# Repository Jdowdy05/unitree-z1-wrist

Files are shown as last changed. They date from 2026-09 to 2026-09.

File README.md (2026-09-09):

# Unitree Z1 wrist

A two-axis, 3D-printable wrist mechanism for the Unitree Z1, using four
ROBOTIS DYNAMIXEL XL330-M288-T servos. Two opposed servos drive each axis through
1:1 connections to their factory horns; there are no external gears or belts.

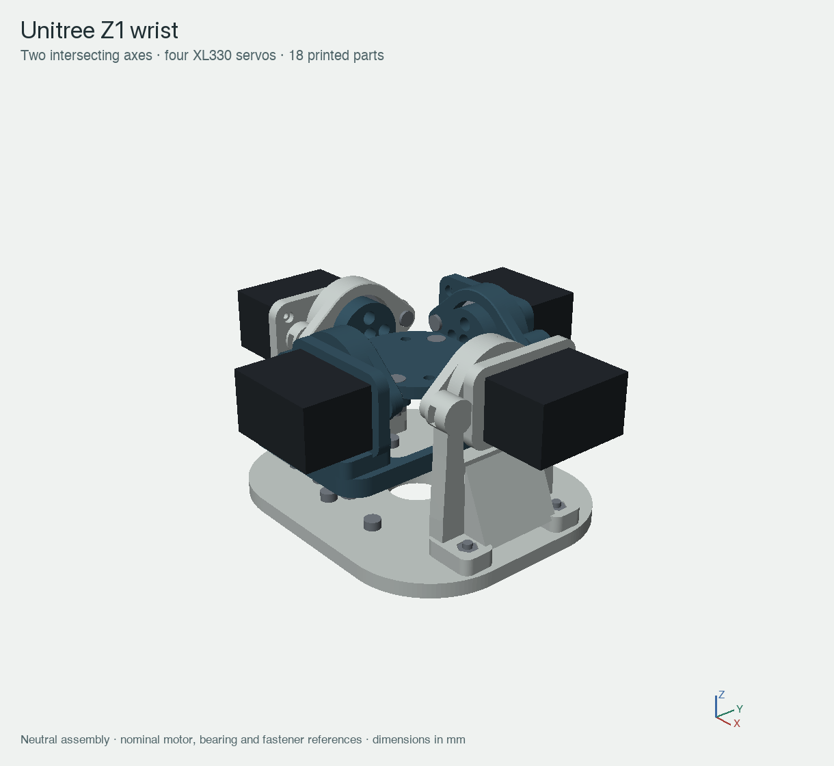
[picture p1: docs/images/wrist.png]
Assembled wrist


**Prototype hardware:** check printed fits, cable clearance and operating loads
before use. No working payload or continuous-duty rating has been established.

## Start here

- **Print:** download the files in [stl/](stl/). Print one of each of the 18 files.
- **Edit in CAD:** open [cad/wrist.step](cad/wrist.step) in your CAD application,
  or [cad/wrist.FCStd](cad/wrist.FCStd) in FreeCAD.
- **Modify individual pieces:** use the named STEP files in [cad/parts/](cad/parts/).
- **Build:** follow the [assembly guide](docs/assembly.md) and [BOM](BOM.csv).
- **Download everything:** use [Download ZIP](https://github.com/Jdowdy05/unitree-z1-wrist/archive/refs/heads/main.zip),
  or clone this repository.

```sh
git clone https://github.com/Jdowdy05/unitree-z1-wrist.git
```

## Layout

```text
cad/
  wrist.FCStd           Native FreeCAD assembly, grouped by part type
  wrist.step            Complete assembly for other CAD applications
  parts/                18 individual printable-part STEP models
  source/
    Rebuild_Wrist.FCMacro
    dimensions.json     Main layout dimensions
  geometry.json         Export inventory, dimensions and mesh checks
stl/                    18 separate meshes in starting print orientations
docs/
  assembly.md           Assembly order, screw locations and print notes
  images/               Assembly and bearing-stack illustrations
BOM.csv                 Mechanical parts and purchased hardware
LICENSE
```

The assembly contains the wrist mechanism, a general-purpose recessed output
plate and nominal reference shapes for motors, bearings and M3 hardware.
The STL directory contains printable parts only. Purchased parts are not
included as printable meshes.

## Main dimensions

| Feature | Nominal value |
| --- | --- |
| Mechanism above the arm mounting face | 128 × 120 × 67 mm |
| Axis intersection / output-plate top | 50.5 mm above the arm mounting face |
| Intended travel | ±25° outer axis, ±20° inner axis |
| Output plate | 44 × 38 mm outline, 4 mm thick |
| General-purpose output pattern | Four Ø3.4 mm holes on a 28 × 14 mm rectangle |
| Nominal Z1 interface | Eight M3 positions on a Ø59.5 mm bolt circle |
| Support bearings | Four 6704 bearings, 20 × 27 × 4 mm |

The output plate's centre lies at the two intersecting axes. Points on an
attached tool away from that centre will move as the plate rotates. The stated
mechanism envelope excludes the screws' intended penetration into the arm.
Verify the actual arm flange and usable thread depth before installation.

## Parts to obtain

| Purchased item | Quantity |
| --- | ---: |
| XL330-M288-T servo, with factory horn | 4 |
| 6704 bearing, 20 mm bore × 27 mm OD × 4 mm wide | 4 |
| M3×8 socket-cap screw | 8 |
| M3×10 socket-cap screw | 12 |
| M3×12 socket-cap screw | 8 |
| M3×12 DIN7991, 90° countersunk screw with 6 mm head | 4 |
| Plain M3 nut, 5.5 mm across flats × 2.4 mm thick | 24 |
| ROBOTIS PHS M2×6 TAP horn screw | 16 |
| ROBOTIS PHS M2×8 TAP body screw | 16 |

These are installed quantities; obtain spares as needed. Check the servo
accessory bags before ordering tapping screws. Keep the factory horns and their
central retaining screws. The [BOM](BOM.csv) includes part-by-part use and sources.

Power, data wiring and a compatible TTL interface are separate from the
mechanical BOM. The XL330 uses 3.7–6.0 V, with 5 V recommended; the Z1's 24 V
supply must not connect directly to these servos. Use properly rated power
distribution and verify paired-motor directions, zero positions and current
sharing before powered operation. See [ROBOTIS documentation](https://emanual.robotis.com/docs/en/dxl/x/xl330-m288/).

## Printing

STLs are centred and placed at Z=0 in suggested starting orientations. They are
not G-code or a validated printer profile. Inspect supports for bearing roofs,
hub flanges, projecting shelves and horizontal holes before slicing. Retainers,
spacers and the output plate have functional flat-face orientations.

PETG is the starting material assumption. Calibrate bearing fits, journals,
nut pockets and screw holes on your printer. Layer direction, supports, walls,
creep and fastener preload affect the real assembly; a closed mesh does not
establish printed strength. Do not print the complete assembled STEP as one part.

## Editing the design

The FreeCAD document contains named solid features organised into printable
parts, purchased reference components and reference fasteners. It does not
contain a solved assembly constraint system or a full Sketcher history.

For reproducible changes, edit [cad/source/dimensions.json](cad/source/dimensions.json)
and the detailed geometry in [Rebuild_Wrist.FCMacro](cad/source/Rebuild_Wrist.FCMacro).
In FreeCAD, open **Macro → Macros**, select `cad/source/` as the macro location,
and run `Rebuild_Wrist`. It uses only standard FreeCAD modules and Python's
standard library, and rewrites the generated CAD and STL files in this repo.
Keep a copy or branch before rebuilding your modifications.

The JSON exposes main layout controls; detailed mounting features are fixed in
the macro. The generator checks connected solids and closed meshes. Changes
still require a new assembly, clearance and hardware-stack review.

## Verification and licence

The published default geometry has been checked as 26 valid component solids
and 18 closed STL meshes, with 56 nominal M3 hardware references. The unpowered
nominal mechanism is screened at 55 combinations of its two axis angles. These
checks do not cover arbitrary intermediate motion, real cables, printing,
load capacity or control behaviour.

Project-authored design files and CAD source are released under the [MIT licence](LICENSE).
Motor, bearing and fastener shapes are simple nominal reference envelopes;
manufacturer CAD is not redistributed here. Product names identify compatibility
and do not imply endorsement.

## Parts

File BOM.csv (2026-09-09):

item | category | quantity | description | part_or_print_file | manufacturer_or_source | specification | assembly_notes | reference_url
01 | Printed | 1 | Arm mounting base | stl/01_arm_base.stl | Project CAD | PETG prototype assumption | 5 mm nominal base thickness; verify actual flange
02 | Printed | 1 | Negative-X ground support | stl/02_outer_support_left.stl | Project CAD | PETG prototype assumption | Preload two foot nuts and two retainer nuts before motor installation
03 | Printed | 1 | Positive-X ground support | stl/03_outer_support_right.stl | Project CAD | PETG prototype assumption | Preload two foot nuts and two retainer nuts before motor installation
04 | Printed | 1 | Negative-X bearing retainer | stl/04_outer_retainer_left.stl | Project CAD | PETG prototype assumption | Two M3x8 screws; captures outer bearing race
05 | Printed | 1 | Positive-X bearing retainer | stl/05_outer_retainer_right.stl | Project CAD | PETG prototype assumption | Two M3x8 screws; captures outer bearing race
06 | Printed | 1 | Negative-X journal shim ring | stl/06_outer_spacer_left.stl | Project CAD | PETG prototype assumption | Nominal ID20.1 x OD22 x axial5 mm; fit without binding
07 | Printed | 1 | Positive-X journal shim ring | stl/07_outer_spacer_right.stl | Project CAD | PETG prototype assumption | Nominal ID20.1 x OD22 x axial5 mm; fit without binding
08 | Printed | 1 | Left outer gimbal half | stl/08_gimbal_left.stl | Project CAD | PETG prototype assumption | Driven hub is integrated; assemble bearing stack before horn fastening
09 | Printed | 1 | Right outer gimbal half | stl/09_gimbal_right.stl | Project CAD | PETG prototype assumption | Driven hub is integrated; assemble bearing stack before horn fastening
10 | Printed | 1 | Negative-Y inner motor cassette | stl/10_inner_cassette_left.stl | Project CAD | PETG prototype assumption | Preload two foot nuts and two retainer nuts before motor installation
11 | Printed | 1 | Positive-Y inner motor cassette | stl/11_inner_cassette_right.stl | Project CAD | PETG prototype assumption | Preload two foot nuts and two retainer nuts before motor installation
12 | Printed | 1 | Negative-Y driven hub and output shelf | stl/12_inner_hub_left.stl | Project CAD | PETG prototype assumption | Retain full bearing shoulder
13 | Printed | 1 | Positive-Y driven hub and output shelf | stl/13_inner_hub_right.stl | Project CAD | PETG prototype assumption | Retain full bearing shoulder
14 | Printed | 1 | Negative-Y bearing retainer | stl/14_inner_retainer_left.stl | Project CAD | PETG prototype assumption | Two M3x8 screws; captures outer bearing race
15 | Printed | 1 | Positive-Y bearing retainer | stl/15_inner_retainer_right.stl | Project CAD | PETG prototype assumption | Two M3x8 screws; captures outer bearing race
16 | Printed | 1 | Negative-Y journal shim ring | stl/16_inner_spacer_left.stl | Project CAD | PETG prototype assumption | Nominal ID20.1 x OD22 x axial5 mm; fit without binding
17 | Printed | 1 | Positive-Y journal shim ring | stl/17_inner_spacer_right.stl | Project CAD | PETG prototype assumption | Nominal ID20.1 x OD22 x axial5 mm; fit without binding
18 | Printed | 1 | Recessed general-purpose output plate | stl/18_output_plate.stl | Project CAD | PETG prototype assumption | 4 mm thick; 44 x38 mm outline; generic 28 x14 mm four-hole pattern
B01 | Purchased | 4 | Thin-section ball bearing | 6704 | Bearing manufacturer matching the listed dimensions | 20 mm bore x27 mm OD x4 mm width | Select and fit-check actual bearing variant; reference dimensions from JTEKT | https://koyo.jtekt.co.jp/en/products/detail/?pno=6704
F01 | Purchased | 8 | Socket-head cap screw | M3x8 | Commercial hardware supplier | 5.5 mm nominal head diameter; 3 mm head height | Two per bearing retainer; length excludes head
F02 | Purchased | 12 | Socket-head cap screw | M3x10 | Commercial hardware supplier | 5.5 mm nominal head diameter; 3 mm head height | Four gimbal-lap screws plus eight arm screws; confirm arm thread depth
F03 | Purchased | 8 | Socket-head cap screw | M3x12 | Commercial hardware supplier | 5.5 mm nominal head diameter; 3 mm head height | Four ground-support feet plus four inner-cassette feet
F04 | Purchased | 4 | Countersunk socket screw | M3x12 DIN7991 countersunk, 90 degree | Commercial hardware supplier | 6 mm nominal head diameter; 1.7 mm nominal head height | Output plate to hub shelves; length includes head; verify purchased head dimensions | https://www.accu.co.uk/countersunk-socket-head-screws/472018-SSK-M3-12-10-9
F05 | Purchased | 24 | Plain hex nut | M3 | Commercial hardware supplier | 5.5 mm across flats x2.4 mm thick | Eight retainer nuts; eight foot nuts; four lap nuts; four output-plate nuts
F06 | Purchased | 16 | Horn tapping screw | PHS M2x6 TAP | ROBOTIS | For 3 mm printed horn-attachment stack | Four per horn; retain factory central screws; do not substitute M2 machine thread | https://emanual.robotis.com/assets/images/dxl/x/x330/x330_horn_screw.png
F07 | Purchased | 16 | Motor-body tapping screw | PHS M2x8 TAP | ROBOTIS | For designated front frame/body mounting passages | Four per motor; verify actual tapping engagement; do not substitute M2 machine thread | https://en.robotis.com/shop_en/item.php?it_id=902-0163-000
M01 | Purchased | 4 | DYNAMIXEL servo | XL330-M288-T | ROBOTIS | 20 x34 x23 mm body; factory horn retained | Includes retained factory horn and central retaining screw; 3.7-6.0 V supply | https://emanual.robotis.com/docs/en/dxl/x/xl330-m288/

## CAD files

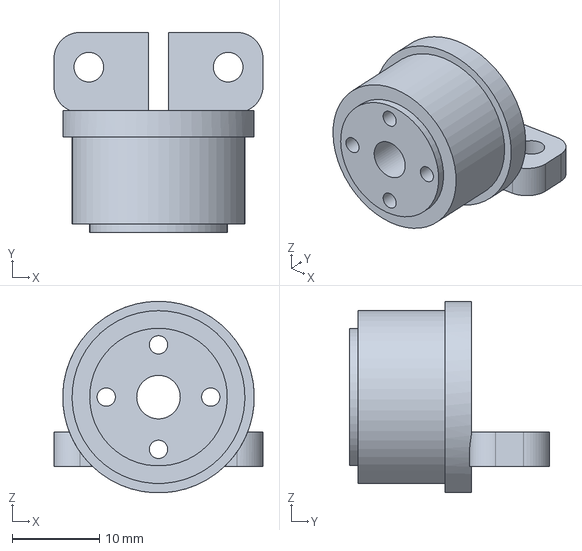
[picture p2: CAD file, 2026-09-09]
cad/parts/12_inner_hub_left.step
24.0 x 23.0 x 22.0 mm

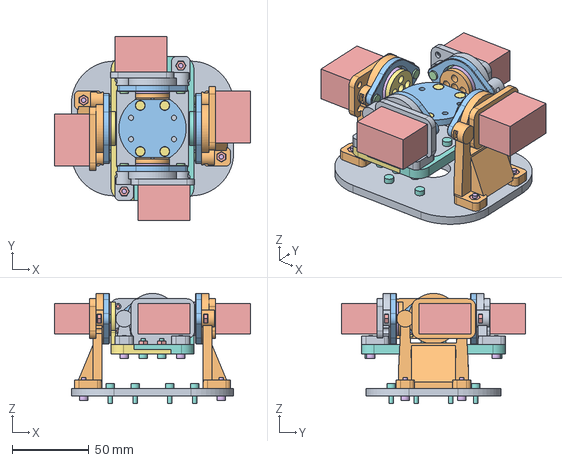
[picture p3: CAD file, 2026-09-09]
cad/wrist.step
128.0 x 120.0 x 72.0 mm

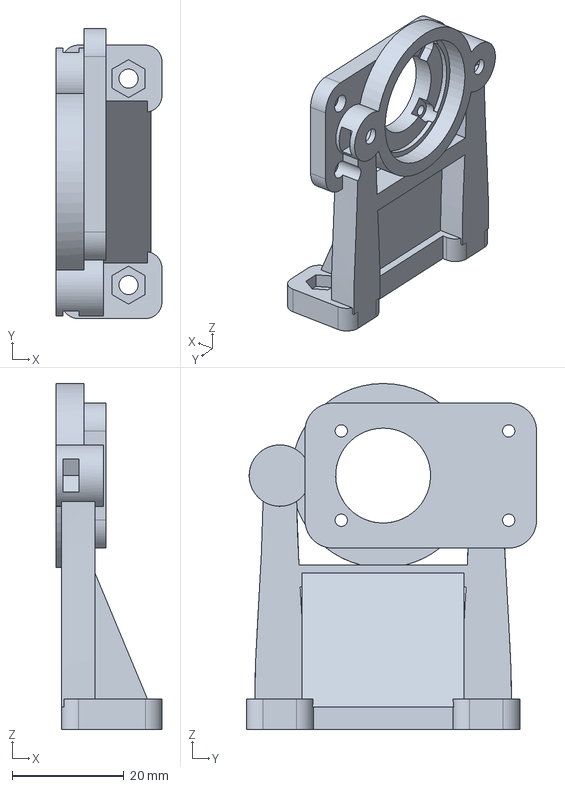
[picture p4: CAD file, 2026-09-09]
cad/parts/03_outer_support_right.step
19.0 x 52.0 x 62.0 mm

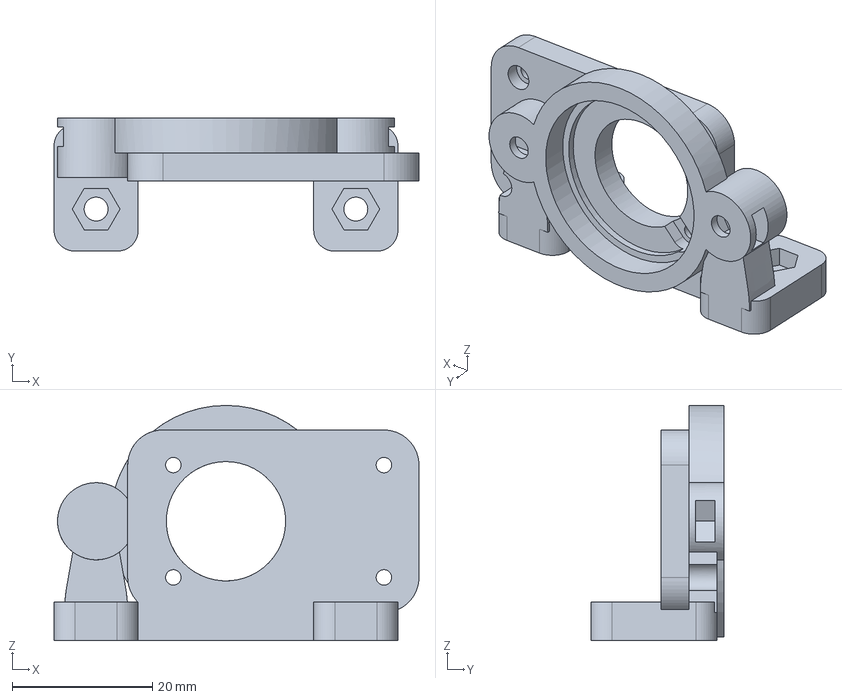
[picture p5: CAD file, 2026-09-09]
cad/parts/10_inner_cassette_left.step
52.0 x 19.0 x 33.5 mm

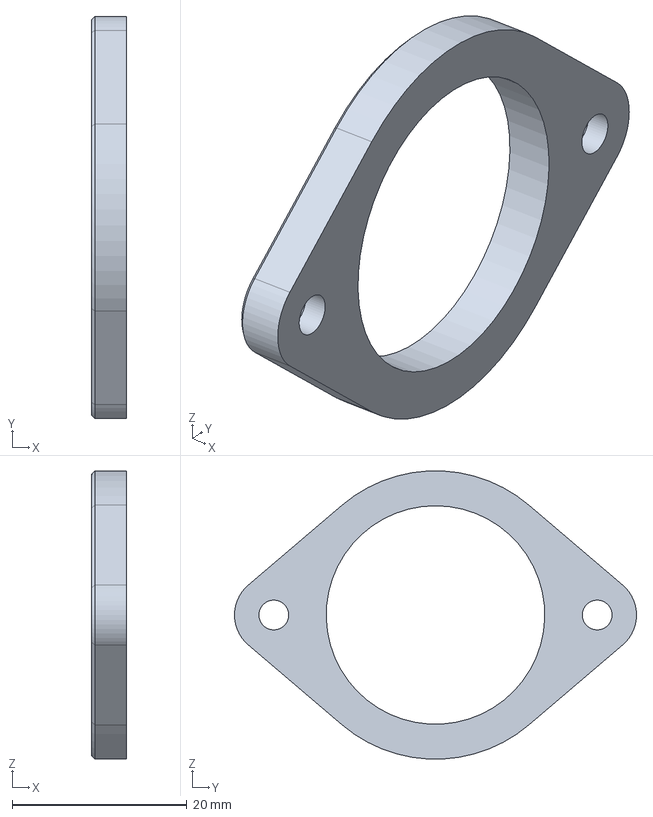
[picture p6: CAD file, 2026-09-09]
cad/parts/05_outer_retainer_right.step
4.00 x 46.0 x 33.0 mm

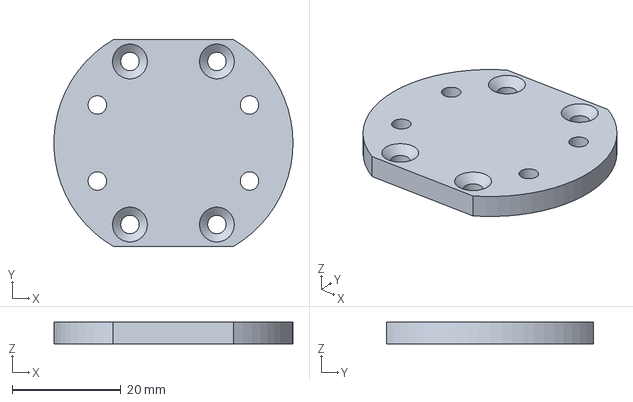
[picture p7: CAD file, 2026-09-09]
cad/parts/18_output_plate.step
44.0 x 38.0 x 4.00 mm

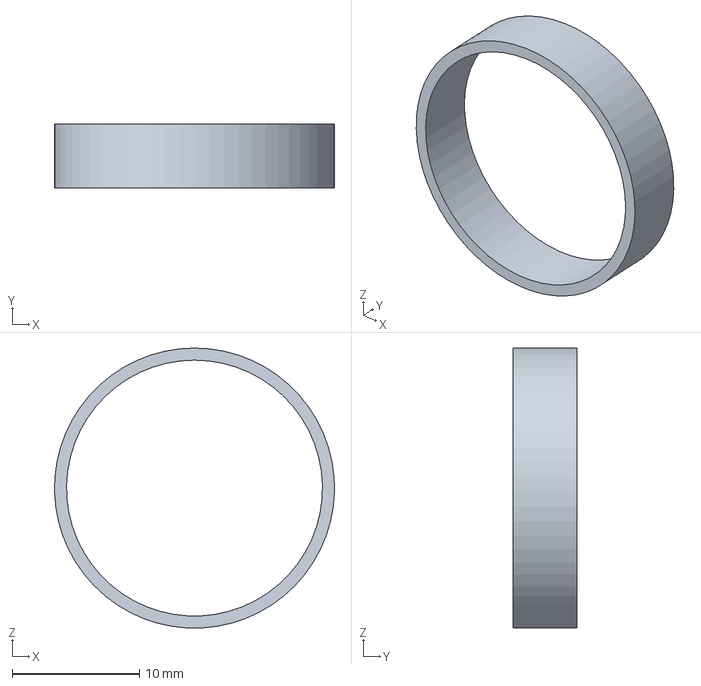
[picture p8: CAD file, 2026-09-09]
cad/parts/16_inner_spacer_left.step
22.0 x 5.00 x 22.0 mm

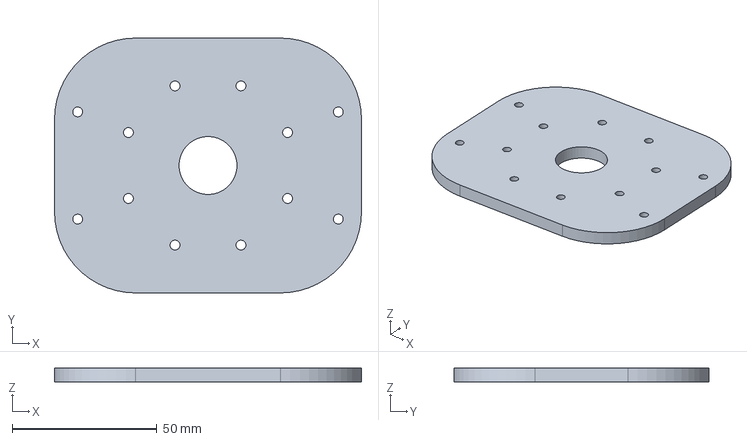
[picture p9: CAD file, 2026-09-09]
cad/parts/01_arm_base.step
106.0 x 88.0 x 5.00 mm

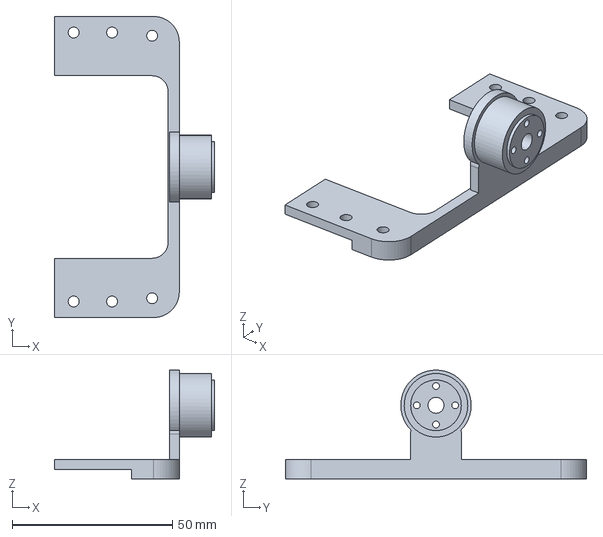
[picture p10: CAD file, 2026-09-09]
cad/parts/09_gimbal_right.step
50.0 x 94.0 x 34.0 mm

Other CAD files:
cad/parts/13_inner_hub_right.step
cad/parts/15_inner_retainer_right.step
cad/parts/02_outer_support_left.step
cad/parts/04_outer_retainer_left.step
cad/parts/08_gimbal_left.step
cad/parts/11_inner_cassette_right.step
cad/parts/14_inner_retainer_left.step
cad/parts/07_outer_spacer_right.step
cad/parts/17_inner_spacer_right.step
cad/parts/06_outer_spacer_left.step
cad/wrist.FCStd
stl/01_arm_base.stl
stl/02_outer_support_left.stl
stl/03_outer_support_right.stl
stl/04_outer_retainer_left.stl
stl/05_outer_retainer_right.stl
stl/06_outer_spacer_left.stl
stl/07_outer_spacer_right.stl
stl/08_gimbal_left.stl
stl/09_gimbal_right.stl
stl/10_inner_cassette_left.stl
stl/11_inner_cassette_right.stl
stl/12_inner_hub_left.stl
stl/13_inner_hub_right.stl
stl/14_inner_retainer_left.stl
stl/15_inner_retainer_right.stl
stl/16_inner_spacer_left.stl
stl/17_inner_spacer_right.stl
stl/18_output_plate.stl

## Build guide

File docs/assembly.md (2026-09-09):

# Two-axis wrist assembly

This is a mechanical prototype with a recessed general-purpose output plate.
Four XL330-M288-T servos drive two intersecting axes, with two opposed servos per
axis. Each factory horn connects to its axis at 1:1; the servo's internal gearbox
remains intact. Physical fits, motor sharing, print strength and payload capacity
must be established on the assembled hardware.

The core contains **18 printed pieces, four servos and four bearings**. See
[BOM.csv](../BOM.csv) for the complete mechanical parts list. The selected M3
hardware is **32 screws and 24 plain nuts**. Motor connections add 16 M2×6 TAP
horn screws and 16 M2×8 TAP body screws; keep the original horns and their central
retaining screws.

Wrist assembly

## Coordinates and interfaces

All dimensions below are millimetres in the neutral assembly. The nominal arm
mounting face is Z=0. The common axis intersection and output-plate top are at
O=(0,0,50.5). The outer axis runs along X; the inner axis runs along Y and moves
with the outer gimbal. The core envelope is 128 ×120 ×67. Intended travel is
±25° outer and ±20° inner, subject to physical cable and clearance checks.

`18_output_plate` is 4 mm thick, with a 44 mm circular outline trimmed to 38 mm
across Y. Four countersunk attachment holes at X±8,Y±15 fasten it to the inner
hub shelves. Four additional Ø3.4 through-holes at X±14,Y±7 form a generic
28 ×14 mm output pattern. The plate centre stays at the common pivot; points
on an attached tool away from that centre move as the wrist rotates.

The nominal arm pattern is eight Ø3.4 clearance holes on a 59.5 mm bolt circle,
starting at 22.5° from +X and repeating every 45°. The 5 mm base and selected
M3×10 screws give 5 mm nominal thread entry. Confirm the actual flange pattern,
usable thread depth, connector protrusions and underside screw clearances before
mounting. Do not use the arm screws if they bottom out.

## Fastener locations

For ± coordinate pairs, use every indicated sign combination. Socket-screw
lengths are measured below the head; countersunk-screw length includes the head.

| Joint | Screws | Position and retention |
| --- | --- | --- |
| Four bearing retainers | 8 × M3×8 socket cap | Two per module, 37 mm apart tangentially, parallel to the servo axis; captive nuts in the closed bosses |
| Ground-support feet | 4 × M3×12 socket cap | X±45,Y±18.5; through the base from below into preloaded foot nuts |
| Inner-cassette feet | 4 × M3×12 socket cap | X±18.5,Y±41; through the gimbal from below into preloaded foot nuts |
| Gimbal half-laps | 4 × M3×10 socket cap | X±6,Y±42; screws from below, plain nuts above the 6 mm combined laps |
| Output plate to inner hubs | 4 × M3×12 countersunk | X±8,Y±15; 4 mm plate +4 mm shelf +2.4 mm nut; 1.6 mm nominal tip projection |
| Arm base | 8 × M3×10 socket cap | 59.5 mm bolt circle; screws from above into the arm, with no loose nuts |

At the neutral pose, all retainer screws lie at Z=50.5. Outer retainers have
axes along X at Y±18.5; inner retainers have axes along Y at X±18.5. The four
printed shim rings fit the driven journals, between their shoulders and the
bearing inner races. The retainers capture the bearing outer races; they must
not squeeze the rotating inner rings.

The nominal M3 socket heads are Ø5.5 ×3 high. Plain nuts are 5.5 across flats and
2.4 thick; captive pockets are 5.9 across flats and 2.8 deep. The DIN7991 output screws
use nominal Ø6 heads, 90° countersinks and 1.7 mm head height. Substituting head
styles, washers or thicker nuts changes the checked stacks.

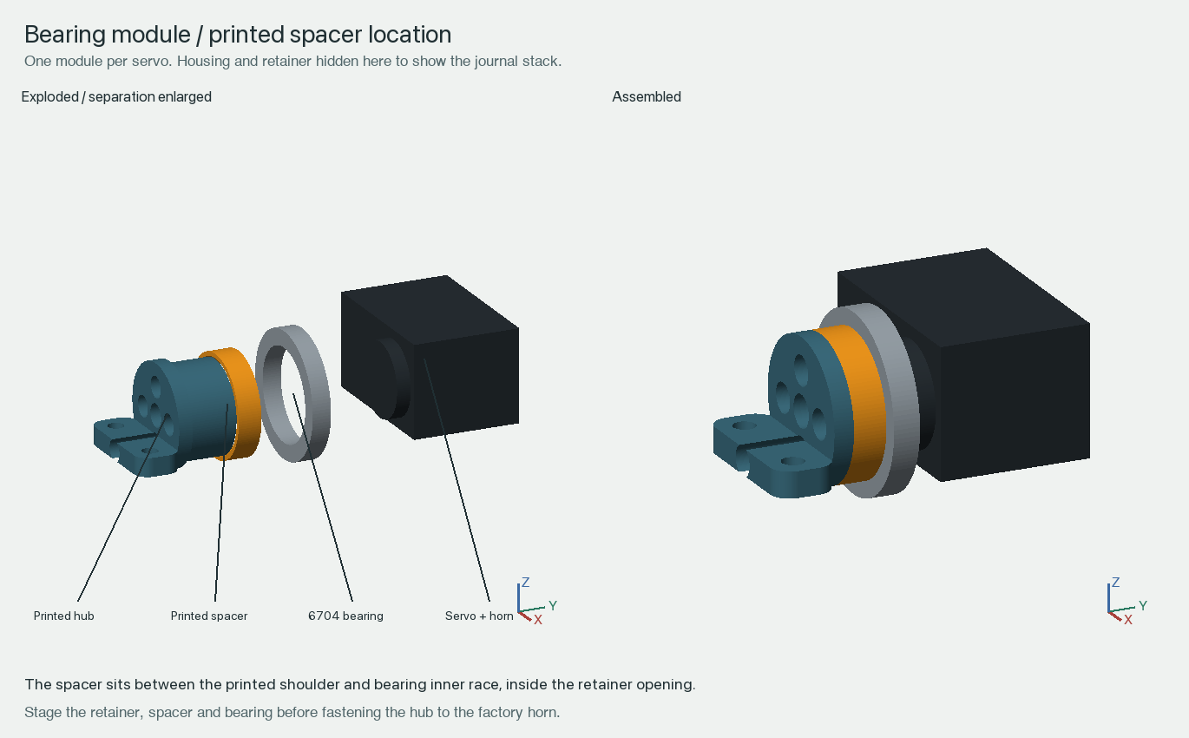
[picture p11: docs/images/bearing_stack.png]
Bearing stack


## Ordered assembly

1. Deburr and fit-check the nut pockets, bearing seats, journals and mating
   faces. Identify left/right pieces in the assembly model. Keep the output
   plate off until the horn screws are accessible and fastened.
2. Preload two foot nuts and two retainer nuts into each empty support/cassette.
   Insert retainer nuts from the side; motors can obstruct later nut insertion.
3. Mount each servo with four M2×8 TAP body screws. Keep its factory horn and
   central retaining screw installed. Do not disturb the case-assembly screws.
4. Stage the retainer, shim ring and 6704 bearing on each free journal before
   attaching it to its horn. The shim seats against the journal shoulder and
   the bearing against the shim. Seat the bearing in the cassette, fasten the
   hub with four M2×6 TAP screws through the open inboard driver channels, then
   fit the two retainer screws. Do not force a bearing over a larger flange.
5. Build both inner hub/cassette modules and attach `18_output_plate` with four
   countersunk M3×12 screws and underside nuts. Heads must sit flush or below
   the plate. Build the two outer support/gimbal-half modules separately while
   their horn-driver paths remain exposed.
6. Bring the outer halves around the inner modules, align the cassette feet
   and close the half-laps. Install four lap screws and four inner-foot screws
   from below. Keep nut access open until every joint is seated.
7. Fit the base-to-arm screws while their top approaches are open, then attach
   the ground-support feet from below. Use a restrained fixture first if the
   actual arm obstructs access.
8. Check screw engagement, bearing seating, free rotation and cable routes
   with power removed. Configure unique servo IDs, directions and zero offsets
   before operating opposed pairs. Commission unloaded at low speed/current,
   checking for binding and unequal effort.

Follow the manufacturer's [XL330 assembly and electrical guidance](https://emanual.robotis.com/docs/en/dxl/x/xl330-m288/).
The horn connection uses a 3 mm printed stack with
[M2×6 TAP screws](https://emanual.robotis.com/assets/images/dxl/x/x330/x330_horn_screw.png).
Do not exceed the permitted horn penetration. The
[XL330 product specification](https://en.robotis.com/shop_en/item.php?it_id=902-0163-000)
lists M2×8 TAP frame screws. The servo supply is 3.7–6.0 V, with 5 V recommended;
never connect these servos directly to a 24 V tool supply.

## Printing and qualification

Orient the annular rings and output plate on suitable flat faces; choose support
and gimbal-half orientations that preserve their functional surfaces and load
paths. The STL files have starting orientations and sit at Z=0; they are not sliced print jobs. Retainers have their head recesses up, rings lie on a ring face, and the output plate has its countersinks up. Supports and frame halves start on their lower faces; the inner hubs have upright journals and require support review around their projecting shelves. Review
perimeters, supports, small nut lands and layer direction on the actual printer.
Use the nominal [6704 bearing dimensions](https://koyo.jtekt.co.jp/en/products/detail/?pno=6704)
(20 mm bore, 27 mm outer diameter, 4 mm width) as a starting interface, then fit
check the selected bearings and printed parts.

CAD validity and sampled clearance checks do not qualify material strength,
preload, creep, repeated loading, control stability or a working payload. Test
an unloaded restrained assembly before adding a tool or commissioning powered
loads. Cabling, power distribution and the control interface are separate from
the mechanical BOM.
